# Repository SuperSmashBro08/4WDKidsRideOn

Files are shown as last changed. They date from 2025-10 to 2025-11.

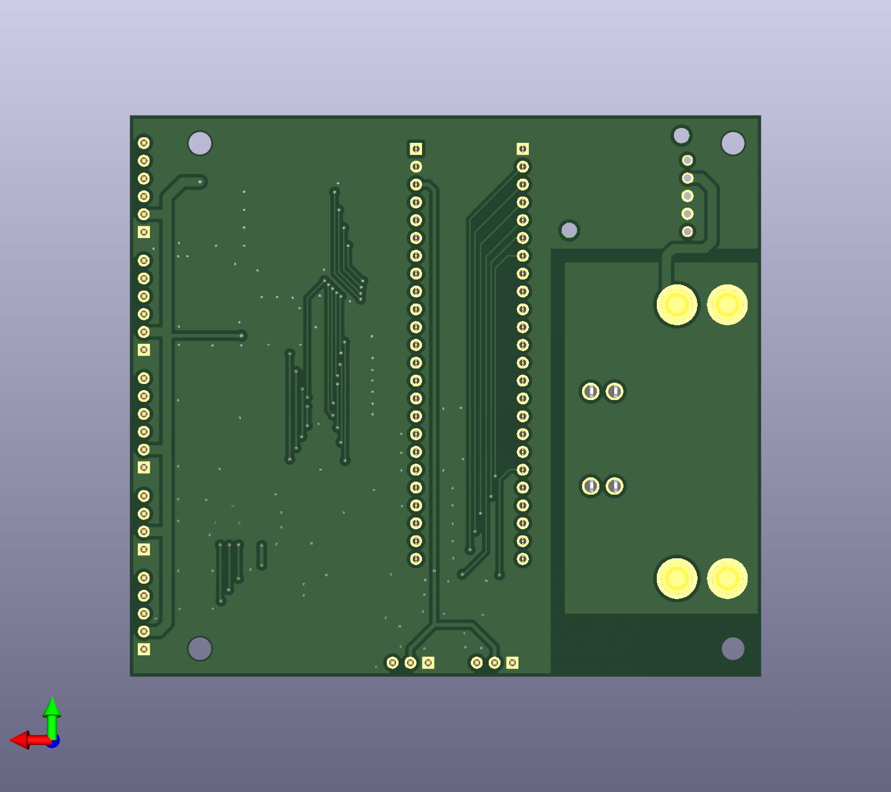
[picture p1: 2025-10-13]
hardware/PCB/Kids Ride On V3/Kids Ride On V3/Pdfs and images/bottom.jpg

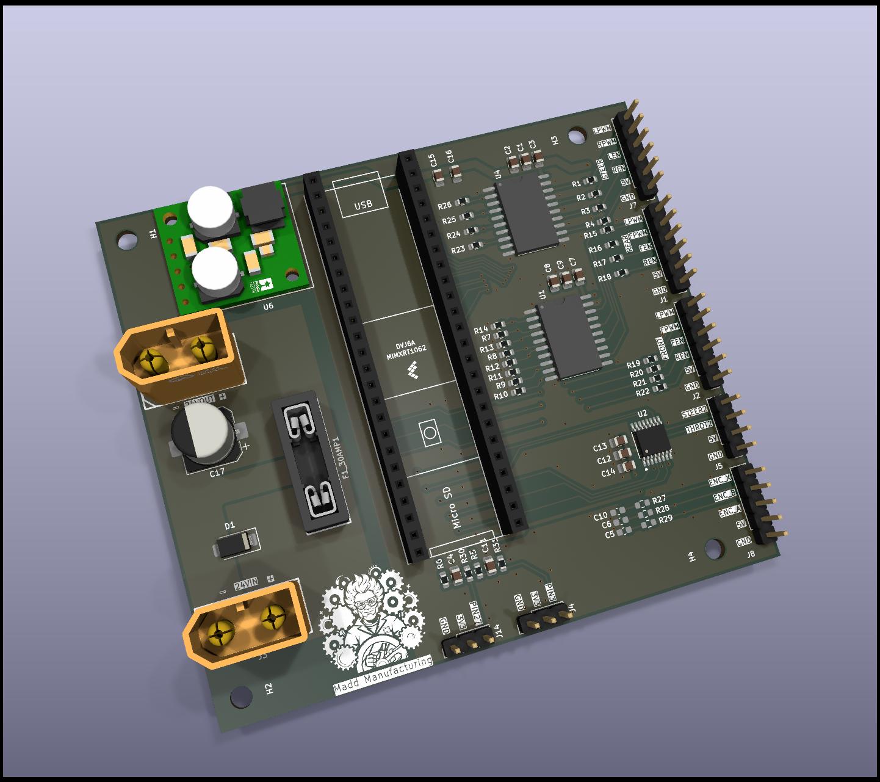
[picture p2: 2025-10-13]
hardware/PCB/Kids Ride On V3/Kids Ride On V3/Pdfs and images/3d.jpg

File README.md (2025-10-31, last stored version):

# ESP32 ↔ Teensy 4.1 OTA Workflow

This repository contains two coordinated sketches that allow an ESP32-S3 to deliver over-the-air
(OTA) firmware updates to a Teensy 4.1-based TNC. The ESP32 hosts a small web page where you upload
the Intel HEX file exported by the Arduino IDE. The Teensy runs a purpose-built stub that
handshakes with the ESP32, receives the HEX records, writes them directly into its internal QSPI
flash, and automatically reboots into the freshly programmed image.

The sections below walk through every step from wiring to flashing.

## Hardware overview

* **Teensy 4.1** running the OTA stub sketch found under `firmware/Teensy41_Target/teensystub`.
* **ESP32-S3** running the uploader sketch in `firmware/ESP32_Uploader/esp32_uploader`.
* **Serial link** – connect ESP32 GPIO43 → Teensy RX2 (pin 7) and ESP32 GPIO44 ← Teensy TX2 (pin 8).
  Share ground between the boards. Keep the wiring short (<15 cm) for clean 115200 baud links.
* **Optional debug USB** – connect the Teensy micro‑USB to a computer to monitor verbose logs while
  testing. The ESP32 USB serial console is also helpful for Wi‑Fi and OTA diagnostics.

## Preparing the firmware

1. Open the Teensy project you want to deploy in the Arduino IDE and select **Teensy 4.1** as the
   target board.
2. Use **Sketch → Export compiled Binary**. This generates a `.hex` file in the sketch folder.
3. (Optional) Rename the HEX file with the build date or version so you can identify it easily on
the ESP32 upload page.

## Building and loading the OTA stub

1. In the Arduino IDE open `firmware/Teensy41_Target/teensystub/teensystub.ino`.
2. Verify that the `OTA_TOKEN` matches the value in `firmware/ESP32_Uploader/esp32_uploader/secrets.h`.
   Changing the token requires reflashing **both** boards.
3. Click **Upload** to flash the stub onto the Teensy 4.1. The stub prints its firmware version and
   provides a small serial console (commands: `help`, `status`, `version`, `reboot`).
4. Leave the stub in place. Every subsequent OTA update will completely replace it with your real
   TNC firmware, so be sure to keep a copy handy if you ever need to revert.

## Flashing workflow (ESP32 as the OTA server)

1. Flash the ESP32 with `firmware/ESP32_Uploader/esp32_uploader.ino`, update Wi‑Fi credentials in
   `secrets.h`, and allow it to join your network. The serial console prints the IP address and the
   optional mDNS hostname (`esp32-teensy.local`).
2. Visit `http://<esp32-ip>/` in a browser. The page exposes a single file upload form.
3. Click **Choose File**, select the Teensy `.hex` binary, and press **Upload & Flash**.
4. The ESP32 performs the following automatically:
   * Opens the serial link to the Teensy and sends `HELLO <token>`.
   * Streams each Intel HEX record line-by-line (`BEGIN HEX`, `L …`, `END`).
   * Displays a live log containing acknowledgements for every line.
5. The Teensy stub validates every record, accumulates data into 4 KB sectors, erases/programs its
   internal flash, and acknowledges each line with `OK <n>`. When the last record arrives it sends a
   summary (`HEX OK …`) followed by `APPLIED`, waits one second, and triggers a software reset to
   boot into the newly flashed firmware.
6. The ESP32 page updates with a success message showing transfer statistics. If anything fails you
   will see the Teensy-provided error reason (checksum mismatch, unsupported record type, flash
   write failure, missing EOF, etc.).

## Recovery and troubleshooting

* If the Teensy reports `HEX FAIL` immediately after `BEGIN HEX`, ensure the `OTA_TOKEN` matches and
  that both boards are wired correctly. Any lingering serial data from previous runs should be
  cleared by resetting the Teensy.
* When a transfer aborts mid-stream, the Teensy keeps the original firmware. The stub only commits
  data after successfully writing each 4 KB sector and it does not reset until the entire image
  passes validation.
* To recover the stub after flashing a faulty firmware, press and hold the Teensy **Program** button
  and upload the stub again from the Arduino IDE via USB. Once the stub is running you can retry the
  OTA process.
* Use the Teensy USB console command `status` to inspect how many lines, bytes, sectors, and pages
  were processed in the most recent session. This mirrors the data returned to the ESP32 uploader.

## Safety notes

* The stub only accepts data inside the Teensy 4.1 flash address window (`0x6000_0000 – 0x6020_0000`).
  Any record outside that range is rejected before any sector is erased.
* Flash programming runs with interrupts temporarily disabled while a page is written. The LED on
  pin 13 continues to heartbeat so you can see the board is alive during a long update.
* After a successful OTA the stub reboots automatically. No additional hardware toggling of the
  Program pin is required.

With the steps above the entire flow—uploading the HEX file, streaming it to the Teensy, flashing,
and rebooting—happens end-to-end without manual intervention.

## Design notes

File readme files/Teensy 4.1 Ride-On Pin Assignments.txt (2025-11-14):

Teensy 4.1 Ride-On Pin Assignments
Steering (J7)
Teensy Pin	Label / Function	Board Header	Motor Controller Label
Pin 15	Steer LPWM	J7-6	Steer L_PWM
Pin 16	Steer RPWM	J7-5	Steer R_PWM
Pin 17	Steer L_EN	J7-4	Steer L_EN
Pin 18	Steer R_EN	J7-3	Steer R_EN

Front Motors (J2)
Teensy Pin	Label / Function	Board Header	Motor Controller Label
Pin 19	Front R_EN	J2-3	Front R_EN
Pin 20	Front L_EN	J2-4	Front L_EN
Pin 21	Front L_PWM	J2-5	Front L_PWM
Pin 22	Front R_PWM	J2-6	Front R_PWM

Rear Motors (J1)
Teensy Pin	Label / Function	Board Header	Motor Controller Label
Pin 23	Rear R_EN	J1-3	Rear R_EN
Pin 24	Rear L_EN	J1-4	Rear L_EN
Pin 25	Rear L_PWM	J1-5	Rear L_PWM
Pin 26	Rear R_PWM	J1-6	Rear R_PWM

Direction Switch (Shift Lever)
Teensy Pin	Label / Function	Board Header	Motor Controller 
Pin 10	Forward		
Pin 11	Reverse		

ESP32 Link (UART for OTA/Telnet)
Teensy Pin	Label / Function	Board Header	Motor Controller
Pin 7	RX2 (to ESP32 TX)		
Pin 8	TX2 (to ESP32 RX)		

Pots (Child Controls)
Teensy Pin	Label / Function	Board Header	Motor Controller
Pin 27	Foot Pedal (Throttle1)		
Pin 3	Steering Wheel (Steering1)		

Remote Override (RC Receiver)
Teensy Pin	Label / Function	Board Header	Motor Controller
Pin 5	Steering2		
Pin 4	Throttle2		

Gearbox Encoder (AMT-102V)
Teensy Pin	Label / Function	Board Header	Motor Controller
Pin 2	Encoder X		
Pin 1	Encoder B		
Pin 0	Encoder A

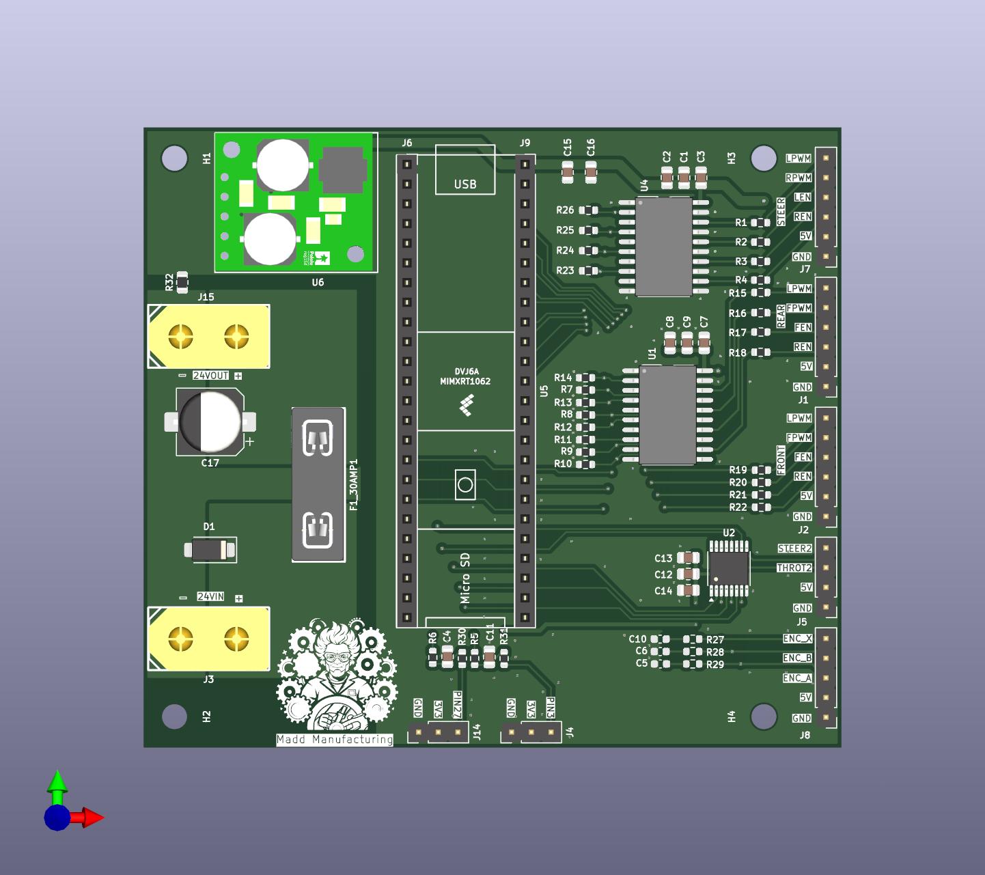
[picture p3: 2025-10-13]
hardware/PCB/Kids Ride On V3/Kids Ride On V3/Pdfs and images/TOP.jpg

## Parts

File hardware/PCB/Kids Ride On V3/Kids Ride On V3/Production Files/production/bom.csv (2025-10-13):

Designator | Footprint | Quantity | Value | LCSC Part #
C1, C11, C12, C15, C4, C7 | 0805 | 6 | 100nF | C49678
C10, C5, C6 | 0603 | 3 | 100pF | C14858
C13, C2, C8 | 0805 | 3 | 1uF | C28323
C14, C3, C9 | 0805 | 3 | 10uF | C15850
C16 | 0805 | 1 | 4.7uF | C98192
C17 | CP_Elec_8x10.5 | 1 | 220uF/35V | C5246556
D1 | D_SMA | 1 | SMAJ33A | C353454
F1_30AMP1 | FUSE-TH_4P-L19.8-W6.7_3557-2 | 1 | Fuse | C352820
J1, J2, J7 | PinHeader_1x06_P2.54mm_Vertical | 3 | Conn_01x06 | C492405
J14, J4 | PinHeader_1x03_P2.54mm_Vertical | 2 | Conn_01x03 | C2937625
J15, J3 | CONN-TH_XT60 | 2 | XT60-M. | C98733
J5 | PinHeader_1x04_P2.54mm_Vertical | 1 | Conn_01x04 | C2691448
J6, J9 | PinSocket_1x24_P2.54mm_Vertical | 2 | Conn_01x24 | C2883741
J8 | PinHeader_1x05_P2.54mm_Vertical | 1 | Conn_01x05 | C492404
R1, R15, R16, R17, R18, R19, R2, R20, R21, R22, R3, R4, R5, R6 | 0603 | 14 | 33R | C108661
R10, R11, R12, R13, R14, R23, R24, R25, R26, R7, R8, R9 | 0603 | 12 | 10k | C98220
R27, R28, R29, R30, R31 | 0603 | 5 | 100R | C105588
R32 | 0805 | 1 | 0R | C100045
U1, U4 | SOIC-20_L12.8-W7.5-P1.27-LS10.3-BL | 2 | SN74AHCT244 | C2675568
U2 | TSSOP-16_4.4x5mm_P0.65mm | 1 | CD74HC4050 | C352825
U6 | D24V50F5 | 1 | D24V50F5 | DNP

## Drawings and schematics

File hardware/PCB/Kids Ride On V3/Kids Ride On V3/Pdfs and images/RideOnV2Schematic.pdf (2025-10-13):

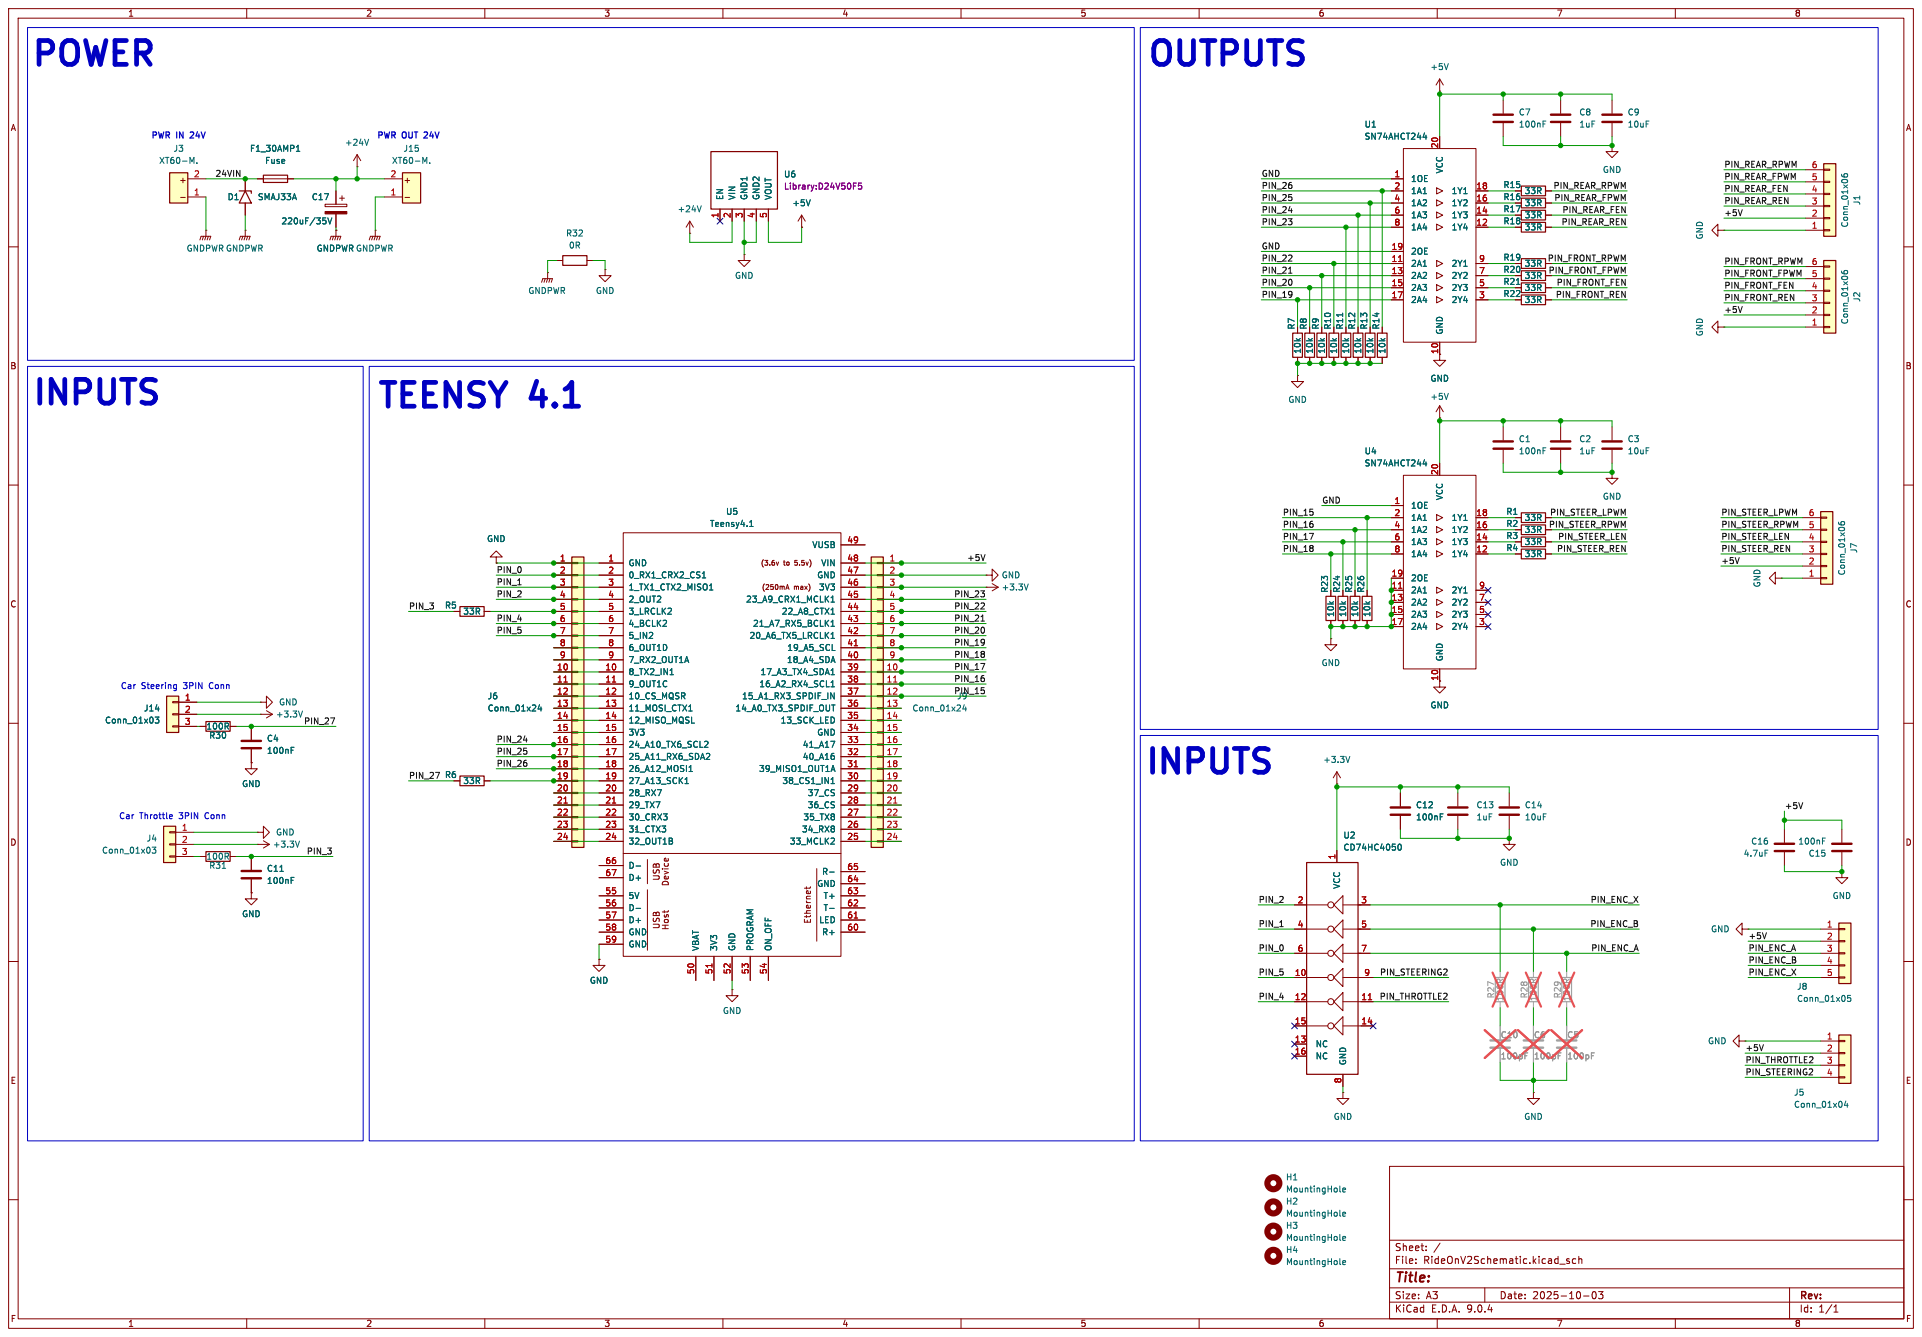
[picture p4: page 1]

Car Throttle 3PIN Conn Car Steering 3PIN Conn INPUTS

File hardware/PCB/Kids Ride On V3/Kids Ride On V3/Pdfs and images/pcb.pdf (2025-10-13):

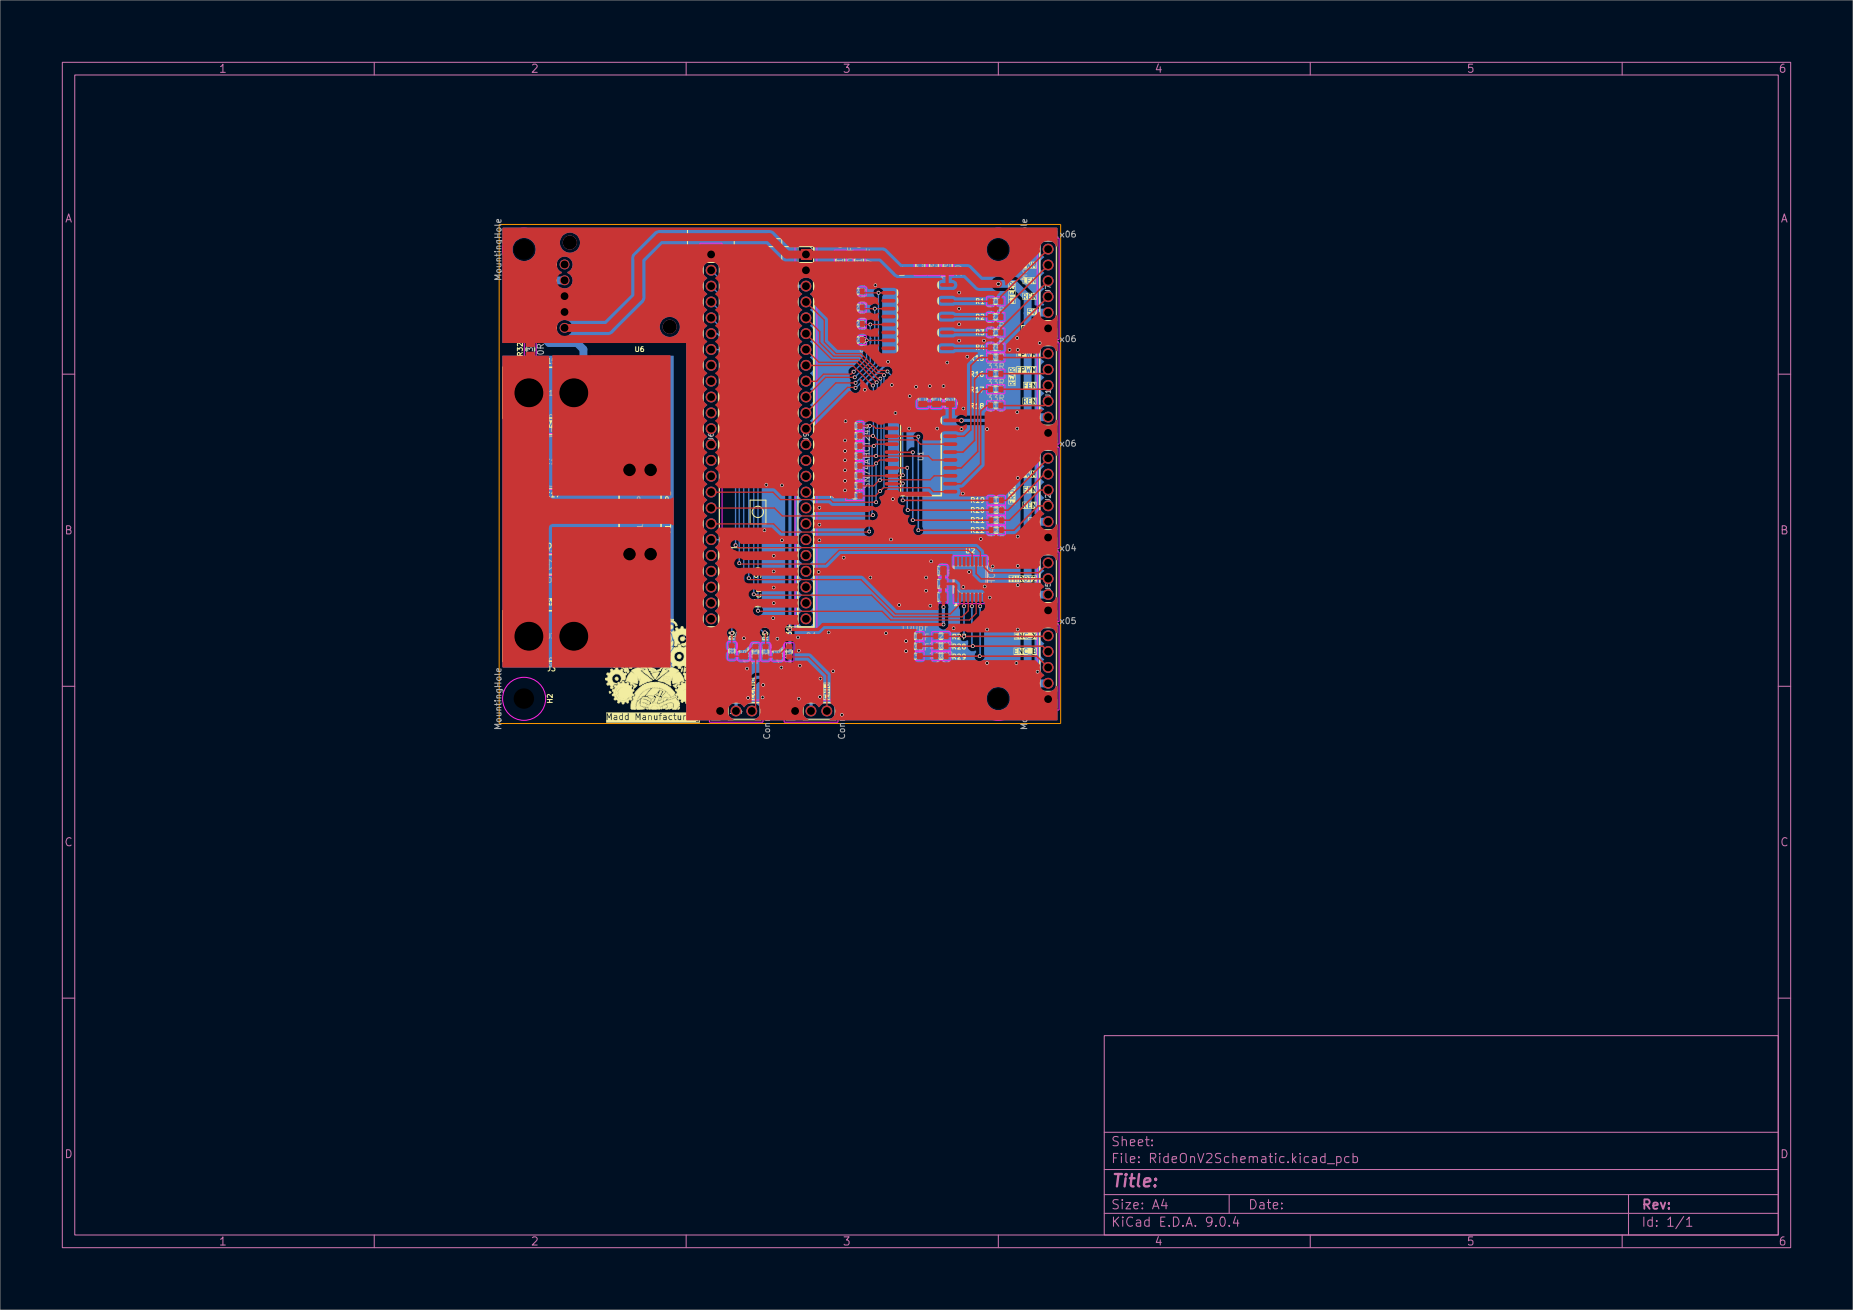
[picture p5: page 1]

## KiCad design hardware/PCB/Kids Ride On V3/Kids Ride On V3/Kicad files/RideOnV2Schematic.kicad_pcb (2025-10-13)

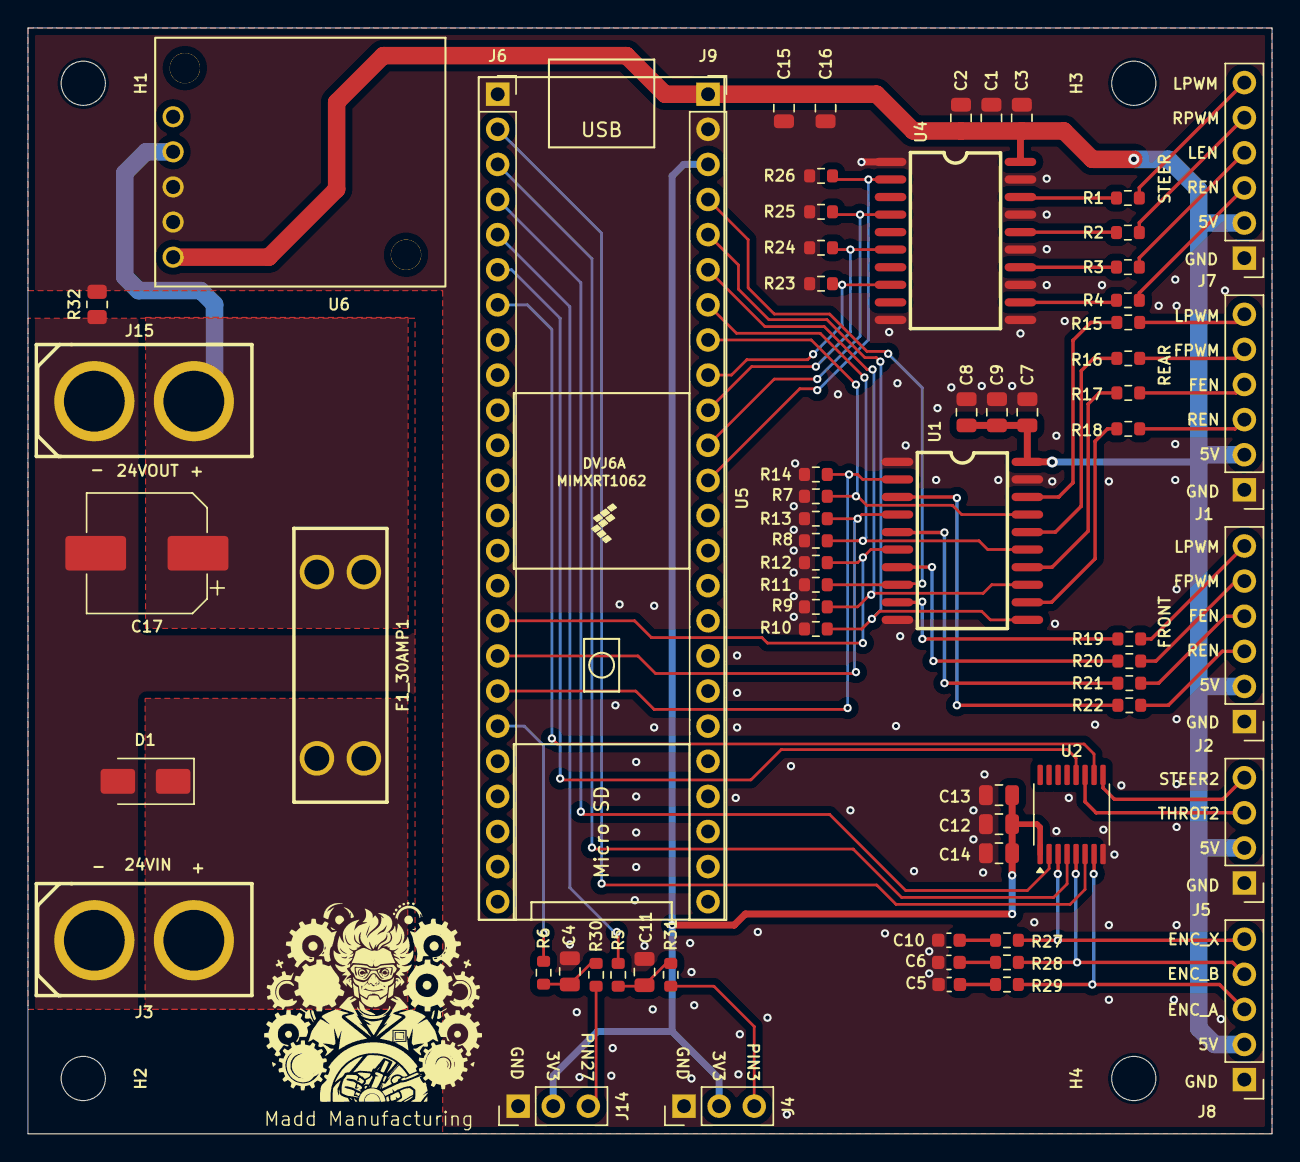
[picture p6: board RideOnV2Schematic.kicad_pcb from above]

Board: 2 copper layers, 90.0 x 80.0 mm, 71 parts (0 on the bottom side), 61 nets.

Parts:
C1, C4, C7, C11, C12, C15: 100nF; C_0805_2012Metric
C2, C8, C13: 1uF; C_0805_2012Metric
C3, C9, C14: 10uF; C_0805_2012Metric
C5, C6, C10: 100pF; C_0603_1608Metric
C16: 4.7uF; C_0805_2012Metric
C17: 220uF/35V; CP_Elec_8x10.5
D1: SMAJ33A; D_SMA
F1_30AMP1: Fuse; FUSE-TH_4P-L19.8-W6.7_3557-2
H1, H2, H3, H4: MountingHole; MountingHole_3.2mm_M3
J1, J2, J7: Conn_01x06; PinHeader_1x06_P2.54mm_Vertical
J3, J15: XT60-M.; CONN-TH_XT60
J4, J14: Conn_01x03; PinHeader_1x03_P2.54mm_Vertical
J5: Conn_01x04; PinHeader_1x04_P2.54mm_Vertical
J6, J9: Conn_01x24; PinSocket_1x24_P2.54mm_Vertical
J8: Conn_01x05; PinHeader_1x05_P2.54mm_Vertical
R1, R2, R3, R4, R5, R6, R15, R16, R17, R18, R19, R20, R21, R22: 33R; R_0603_1608Metric
R7, R8, R9, R10, R11, R12, R13, R14, R23, R24, R25, R26: 10k; R_0603_1608Metric
R27, R28, R29, R30, R31: 100R; R_0603_1608Metric
R32: 0R; R_0805_2012Metric
U1, U4: SN74AHCT244; SOIC-20_L12.8-W7.5-P1.27-LS10.3-BL
U2: CD74HC4050; TSSOP-16_4.4x5mm_P0.65mm
U5: Teensy4.1; Teensy41
U6: D24V50F5

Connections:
+3.3V: C12.1, C13.1, C14.1, J4.2, J9.3, J14.2, U2.1 (VCC)
+5V: C1.1, C2.1, C3.1, C7.1, C8.1, C9.1, C15.2, C16.2, J1.2, J2.2, J5.2, J7.2, J8.2, J9.1, U1.20 (VCC), U4.20 (VCC), U6.5 (VOUT)
+24V: C17.1, F1_30AMP1.1, J15.2, U6.2 (VIN)
/24VIN: D1.1 (A1), F1_30AMP1.2, J3.2
/PIN_0: J6.2, U2.6
/PIN_1: J6.3, U2.4
/PIN_2: J6.4, U2.2
/PIN_3: C11.1, R5.1, R31.1
/PIN_4: J6.6, U2.12
/PIN_5: J6.7, U2.10
/PIN_15: J9.12, R26.1, U4.2 (1A1)
/PIN_16: J9.11, R25.1, U4.4 (1A2)
/PIN_17: J9.10, R24.1, U4.6 (1A3)
/PIN_18: J9.9, R23.1, U4.8 (1A4)
/PIN_19: J9.8, R7.1, U1.17 (2A4)
/PIN_20: J9.7, R8.1, U1.15 (2A3)
/PIN_21: J9.6, R9.1, U1.13 (2A2)
/PIN_22: J9.5, R10.1, U1.11 (2A1)
/PIN_23: J9.4, R11.1, U1.8 (1A4)
/PIN_24: J6.16, R12.1, U1.6 (1A3)
/PIN_25: J6.17, R13.1, U1.4 (1A2)
/PIN_26: J6.18, R14.1, U1.2 (1A1)
/PIN_27: C4.1, R6.1, R30.1
/PIN_ENC_A: J8.3, R29.2, U2.7
/PIN_ENC_B: J8.4, R28.2, U2.5
/PIN_ENC_X: J8.5, R27.2, U2.3
/PIN_FRONT_FEN: J2.4, R21.2
/PIN_FRONT_FPWM: J2.5, R20.2
/PIN_FRONT_REN: J2.3, R22.2
/PIN_FRONT_RPWM: J2.6, R19.2
/PIN_REAR_FEN: J1.4, R17.2
/PIN_REAR_FPWM: J1.5, R16.2
/PIN_REAR_REN: J1.3, R18.2
/PIN_REAR_RPWM: J1.6, R15.2
/PIN_STEERING2: J5.4, U2.9
/PIN_STEER_LEN: J7.4, R3.2
/PIN_STEER_LPWM: J7.6, R1.2
/PIN_STEER_REN: J7.3, R4.2
/PIN_STEER_RPWM: J7.5, R2.2
/PIN_THROTTLE2: J5.3, U2.11
GND: C1.2, C2.2, C3.2, C4.2, C5.2, C6.2, C7.2, C8.2, C9.2, C10.2, C11.2, C12.2, C13.2, C14.2, C15.1, C16.1, J1.1, J2.1, J4.1, J5.1, J6.1, J7.1, J8.1, J9.2, J14.1, R7.2, R8.2, R9.2, R10.2, R11.2, R12.2, R13.2, R14.2, R23.2, R24.2, R25.2, R26.2, R32.2, U1.1 (1OE), U1.10 (GND), U1.19 (2OE), U2.8 (GND), U4.1 (1OE), U4.10 (GND), U4.11 (2A1), U4.13 (2A2), U4.15 (2A3), U4.17 (2A4), U4.19 (2OE), U6.3 (GND1), U6.4 (GND2)
GNDPWR: C17.2, D1.2 (A2), J3.1, J15.1, R32.1
unnamed: C5.1, R29.1
unnamed: C6.1, R28.1
unnamed: C10.1, R27.1
unnamed: J4.3, R31.2
unnamed: J6.5, R5.2
unnamed: J6.19, R6.2
unnamed: J14.3, R30.2
unnamed: R15.1, U1.18 (1Y1)
unnamed: R16.1, U1.16 (1Y2)
unnamed: R17.1, U1.14 (1Y3)
unnamed: R18.1, U1.12 (1Y4)
unnamed: R19.1, U1.9 (2Y1)
unnamed: R20.1, U1.7 (2Y2)
unnamed: R21.1, U1.5 (2Y3)
unnamed: R22.1, U1.3 (2Y4)
unnamed: R1.1, U4.18 (1Y1)
unnamed: R2.1, U4.16 (1Y2)
unnamed: R3.1, U4.14 (1Y3)
unnamed: R4.1, U4.12 (1Y4)

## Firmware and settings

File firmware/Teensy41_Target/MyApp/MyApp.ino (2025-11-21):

// ============ MyApp.ino  ============
//
// Features:
// - RAW snapshot line every ~30 ms: S1/T1/S2/T2/FNR/AS + throttle levels (both sources, raw view)
// - STEER line: steering target (L/C/R), current angle, steer source, throttle source, drive ON/OFF
// - THR line: effective throttle source (T1/T2) and speed level OFF/LOW/MED/HIGH
// - DRIVE logic:
//      • FNR = neutral → drive OFF
//      • FNR = forward → M1/M2 drive forward at OFF/LOW/MED/HIGH
//      • FNR = reverse → M1/M2 drive reverse at OFF/LOW/MED/HIGH
//      • Only the active throttle source (ThrSrc) affects drive speed
// - ESP32 angle stream over Serial2 via OtaUpdater hook
//   expected line from ESP32: "AS,<raw>,<deg>"
// - Steering motor driver: BTS7960 on pins 15..18 (LPWM/RPWM/L_EN/R_EN)
// - Front (M1) and Rear (M2) drive BTS7960 on pins 19..26
// - Steering selection by thirds (S1 or S2):
//      S1: 420..2870 (left/center/right thirds)
//      S2: 1000..2000 µs (left/center/right thirds)
// - Throttle shaping:
//      • T1 pedal raw window: 1108 = Off, 3140 = Full
//        - mapped 0..1000 only across [1108..3140]
//        - <=30 in that normalized space = Off (Lv0), rest → Lv1/Lv2/Lv3
//      • T2 RC: signed around 1500 µs, magnitude → Lv1/Lv2/Lv3
// - Control source switching:
//      • Default source: S1/T1
//      • Hold T2 reverse (≤1200 µs) for 3 s → switch to S2/T2
//      • After handover, T2 must pass through neutral to arm
//      • When S2 and T2 both sit near neutral (~1500 ± 40 µs) for 10 s
//        → auto-return to S1/T1, regardless of S1/T1 state
// - Steering motor drive is disabled by default (STEER_DRIVE_ENABLE=0)
//
// =============================================

#ifndef ENABLE_TEENSY_BINARY_TELEM
#define ENABLE_TEENSY_BINARY_TELEM 0
#endif

#include <Arduino.h>
#include <stdarg.h>
#include <string.h>
#include <math.h>
#include <limits.h>
#include "OtaUpdater.h"
#include "OtaConsole.h"

#ifndef IRAM_ATTR
#define IRAM_ATTR
#endif
#ifndef digitalReadFast
#define digitalReadFast digitalRead
#endif

// ---------- App identity ----------
#define APP_FW_VERSION   "V 3.6.1"

// ---------- Blink ----------
#define LED_PIN          13
#define BLINK_MS         500

// ---------- Raw-mirror mode switch ----------
#define RAW_MIRROR_MODE  1   // keep raw stream on

// ---------- IO pins ----------
// Gear F/N/R switch inputs (active LOW with pullups)
static constexpr uint8_t PIN_FWD    = 10;
static constexpr uint8_t PIN_REV    = 11;

// Steering 1 and Throttle 1 (analog)
static constexpr uint8_t PIN_POT_S1 = 14;  // steering analog (wheel/pot)
static constexpr uint8_t PIN_POT_T1 = 27;  // throttle analog (foot pedal)

// RC steering/throttle (S2/T2) PWM inputs
static constexpr uint8_t PIN_RC_S   = 4;   // RC steer PWM in (S2)
static constexpr uint8_t PIN_RC_T   = 5;   // RC throttle PWM in (T2)

// Steering BTS7960 (steer motor)
static constexpr uint8_t PIN_STEER_LPWM = 15;  // J7-6
static constexpr uint8_t PIN_STEER_RPWM = 16;  // J7-5
static constexpr uint8_t PIN_STEER_LEN  = 17;  // J7-4
static constexpr uint8_t PIN_STEER_REN  = 18;  // J7-3

// Drive motor outputs (M1 Front, M2 Rear)
// Front Motors (M1)
static constexpr uint8_t PIN_M1_R_EN  = 19;  // J2-3  Front R_EN
static constexpr uint8_t PIN_M1_L_EN  = 20;  // J2-4  Front L_EN
static constexpr uint8_t PIN_M1_L_PWM = 21;  // J2-5  Front L_PWM
static constexpr uint8_t PIN_M1_R_PWM = 22;  // J2-6  Front R_PWM

// Rear Motors (M2)
static constexpr uint8_t PIN_M2_R_EN  = 23;  // J1-3  Rear R_EN
static constexpr uint8_t PIN_M2_L_EN  = 24;  // J1-4  Rear L_EN
static constexpr uint8_t PIN_M2_L_PWM = 25;  // J1-5  Rear L_PWM
static constexpr uint8_t PIN_M2_R_PWM = 26;  // J1-6  Rear R_PWM

// ---------- ADC helpers ----------
static constexpr float    ADC_VREF    = 3.3f;
static constexpr int      ADC_MAX     = 4095;

// ---------- Logging sink control ----------
enum class LogSink : uint8_t { OTA, USB, BOTH };
static LogSink g_logSink = LogSink::OTA;   // OTA-only by default

// Force every line sent to ESP32 console to start with "S "
static void LOG_raw(const char* s){
  const bool alreadyS = (s && s[0]=='S' && s[1]==' ');
  if (g_logSink==LogSink::OTA || g_logSink==LogSink::BOTH){
    if (alreadyS) OtaConsole::printf("%s", s);
    else          OtaConsole::printf("S %s", s);
  }
  if (g_logSink==LogSink::USB || g_logSink==LogSink::BOTH) Serial.print(s);
}
static void SLOGF(const char* fmt, ...){
  char buf[256];
  va_list ap; va_start(ap, fmt); vsnprintf(buf, sizeof(buf), fmt, ap); va_end(ap);
  LOG_raw(buf);
}

// ================= NAMESPACE MM =================
namespace MM {

// ===== Gear / FNR =====
enum FnrState : uint8_t { FNR_NEU=0, FNR_FWD=1, FNR_REV=2, FNR_FAULT=3 };
static FnrState g_fnr = FNR_NEU;
static inline const char* fnrWord(FnrState s){
  switch(s){ case FNR_FWD: return "forward"; case FNR_REV: return "reverse";
             case FNR_NEU: return "neutral"; default: return "fault"; }
}

// ===== Live values =====
static uint16_t g_s1=0, g_t1=0;                  // raw analog (S1 wheel, T1 pedal)
static volatile uint32_t rcS_rise_us=0, rcS_last_update_us=0;
static volatile uint16_t rcS_width_us=1500;      // S2 µs
static volatile uint32_t rcT_rise_us=0, rcT_last_update_us=0;
static volatile uint16_t rcT_width_us=1500;      // T2 µs
static int16_t  g_s2_us=1500, g_t2_us=1500;      // copies each tick

// ===== RC PWM capture (interrupt) =====
static constexpr uint16_t RC_MIN_US=1000, RC_MID_US=1500, RC_MAX_US=2000, RC_DB_US=20;

static void IRAM_ATTR isrRcSteer(){
  uint32_t now=micros();
  if(digitalReadFast(PIN_RC_S)) rcS_rise_us=now;
  else {
    uint32_t w=now-rcS_rise_us;
    if(w<=3000){
      rcS_width_us=(uint16_t)w;
      rcS_last_update_us=now;
    }
  }
}
static void IRAM_ATTR isrRcThrottle(){
  uint32_t now=micros();
  if(digitalReadFast(PIN_RC_T)) rcT_rise_us=now;
  else {
    uint32_t w=now-rcT_rise_us;
    if(w<=3000){
      rcT_width_us=(uint16_t)w;
      rcT_last_update_us=now;
    }
  }
}

// ===== Convenience maps =====
static inline int16_t clamp_i16(int32_t v, int16_t lo, int16_t hi){
  if(v<lo) return lo;
  if(v>hi) return hi;
  return (int16_t)v;
}

static inline int16_t mapRcSteer_us_to_1000(int16_t us){
  if(us<RC_MIN_US) us=RC_MIN_US;
  if(us>RC_MAX_US) us=RC_MAX_US;
  int32_t x=(int32_t)us-RC_MID_US;
  if (abs(x)<=RC_DB_US) return 0;
  return clamp_i16((x*1000)/(RC_MAX_US-RC_MID_US), -1000, 1000);
}

// Throttle-2: raw-to-0..1000 (forward magnitude helper)
static inline int16_t mapRcThr_us_to_1000(int16_t us){
  if(us<RC_MIN_US) us=RC_MIN_US;
  if(us>RC_MAX_US) us=RC_MAX_US;
  int32_t out=((int32_t)us-RC_MIN_US)*1000/(RC_MAX_US-RC_MIN_US);
  if(out<0)out=0;
  if(out>1000)out=1000;
  return (int16_t)out;
}

// Throttle-2: signed around 1500 µs: -1000 .. 0 .. +1000
static inline int16_t mapRcThrSigned_us_to_1000(int16_t us){
  if(us<RC_MIN_US) us=RC_MIN_US;
  if(us>RC_MAX_US) us=RC_MAX_US;
  int32_t x = (int32_t)us - RC_MID_US;
  if (abs(x) <= RC_DB_US) return 0;
  int32_t span = (RC_MAX_US - RC_MID_US);
  int32_t v = (x * 1000) / span;
  return clamp_i16(v, -1000, 1000);
}

// T1 raw window: 1108 (off) to 3140 (full)
static constexpr uint16_t T1_MIN_RAW = 1108;
static constexpr uint16_t T1_MAX_RAW = 3140;

// T1 mapped to 0..1000 but only across [T1_MIN_RAW..T1_MAX_RAW]
static inline int16_t mapT1_to_1000(uint16_t t1raw){
  if (t1raw <= T1_MIN_RAW) return 0;
  if (t1raw >= T1_MAX_RAW) return 1000;
  uint32_t num = (uint32_t)(t1raw - T1_MIN_RAW) * 1000u;
  uint32_t den = (uint32_t)(T1_MAX_RAW - T1_MIN_RAW);
  return (int16_t)(num / den);
}

// ===== Samples =====
static void sampleAnalog(){
  g_s1=analogRead(PIN_POT_S1);
  g_t1=analogRead(PIN_POT_T1);
}
static void sampleFnr(){
  const bool fwd_low=(digitalRead(PIN_FWD)==LOW), rev_low=(digitalRead(PIN_REV)==LOW);
  if( fwd_low &&  rev_low) g_fnr=FNR_FAULT;
  else if( fwd_low && !rev_low) g_fnr=FNR_FWD;
  else if(!fwd_low &&  rev_low) g_fnr=FNR_REV;
  else g_fnr=FNR_NEU;
}

} // namespace MM

// ======= Angle stream (from ESP32) + helpers ==================================
static volatile uint16_t g_as_raw = 0;
static volatile float    g_as_deg = NAN;
static volatile uint32_t g_as_ms  = 0;

static inline bool angleFresh(uint32_t maxAgeMs);
static bool angleSnapshot(uint16_t& rawOut, float& degOut);

extern "C" bool OtaUserHandleLine(const char* line) {
  if (!line || !*line) return false;
  if (strcmp(line, "PING") == 0) {
    Serial2.println("PONG");
    return true;
  }
  if (strcmp(line, "VERSION") == 0) {
    Serial2.print("FW "); Serial2.println(APP_FW_VERSION);
    Serial2.println("FLASHERX READY");
    return true;
  }

  // Angle packets from ESP32: AS,<raw>,<deg>
  if (line[0]=='A' && line[1]=='S' && line[2]==',') {
    const char* p = line + 3;
    const char* comma = strchr(p, ',');
    if (!comma) return false;
    uint16_t raw = (uint16_t)strtoul(p, nullptr, 10);
    float    deg = atof(comma + 1);
    noInterrupts();
    g_as_raw=raw;
    g_as_deg=deg;
    g_as_ms=millis();
    interrupts();
    return true;
  }
  return false;
}

static inline bool angleFresh(uint32_t maxAgeMs) {
  uint32_t age = millis() - g_as_ms;
  return (g_as_ms != 0) && (age <= maxAgeMs) && !isnan(g_as_deg);
}
static bool angleSnapshot(uint16_t& rawOut, float& degOut) {
  uint16_t raw; float deg; uint32_t stamp;
  noInterrupts();
  raw=g_as_raw; deg=g_as_deg; stamp=g_as_ms;
  interrupts();
  if (stamp == 0 || isnan(deg)) return false;
  if ((millis() - stamp) > 200)  return false;
  rawOut = raw;
  degOut = deg;
  return true;
}

// ======= Telemetry (optional binary to ESP32) ==================================
static inline int16_t toCenti(float v){
  float scaled = v * 100.0f;
  scaled += (scaled >= 0.0f) ? 0.5f : -0.5f;
  long val = (long)scaled;
  if (val > INT16_MAX) val = INT16_MAX;
  if (val < INT16_MIN) val = INT16_MIN;
  return (int16_t)val;
}

#if ENABLE_TEENSY_BINARY_TELEM
// (binary telemetry omitted)
#endif

// ====================== LIMITS / THIRDS ======================
#define AS_LIMITS_SOURCE   1   // 0 = RAW ticks, 1 = degrees
#define AS_LEFT_RAW_PHOTO   1465
#define AS_RIGHT_RAW_PHOTO  2300
#define AS_CENTER_RAW_PHOTO ((AS_LEFT_RAW_PHOTO+AS_RIGHT_RAW_PHOTO)/2)
#define AS_LEFT_DEG_PHOTO    129.00f
#define AS_RIGHT_DEG_PHOTO   202.00f
#define AS_CENTER_DEG_PHOTO  ((AS_LEFT_DEG_PHOTO+AS_RIGHT_DEG_PHOTO)*0.5f)

static const float LIMIT_SOFT_CUSHION_DEG = 2.5f;
static const float LIMIT_HARD_CUSHION_DEG = 0.8f;

static inline float ticksToDeg_u12(uint16_t t12){
  return (360.0f * (float)t12) / 4096.0f;
}

// ====================== CONTROL SOURCE / THROTTLE LEVELS ======================
enum class SteerSrc : uint8_t { S1, S2 };
enum class ThrSrc   : uint8_t { T1, T2 };
static SteerSrc g_steerSrc = SteerSrc::S1;   // default
static ThrSrc   g_thrSrc   = ThrSrc::T1;     // default

// 4-level throttle classification (0=Off,1=Low,2=Med,3=High)
static int8_t g_t1Level = 0;   // always start OFF
static int8_t g_t2Level = 0;   // always start OFF

// Your S1 thirds: 420..2870
static constexpr uint16_t S1_MIN = 420;
static constexpr uint16_t S1_MAX = 2870;
// S2 thirds: 1000..2000 µs
static constexpr uint16_t S2_MIN = 1000;
static constexpr uint16_t S2_MAX = 2000;

// Cut points: [MIN .. LEFT_END) | [LEFT_END .. CENTER_END) | [CENTER_END .. MAX]
static inline void thirds_u16(uint16_t lo, uint16_t hi, uint16_t& L_end, uint16_t& C_end){
  uint32_t span = (uint32_t)hi - (uint32_t)lo;
  uint16_t third = (uint16_t)(span / 3u);
  L_end = (uint16_t)(lo + third);
  C_end = (uint16_t)(lo + 2u*third);
}
static uint16_t S1_LEFT_END=0, S1_CENTER_END=0;
static uint16_t S2_LEFT_END=0, S2_CENTER_END=0;

// Hand-over conditions
static constexpr uint16_t RC_REVERSE_THRESH_US = 1200;    // ≤ this is reverse
static constexpr uint32_t RC_REVERSE_HOLD_MS   = 3000;    // 3 s
static uint32_t g_rcReverseStartMs = 0;

// Neutral detection (deadbands)
static constexpr uint16_t T2_NEUTRAL_DB_US   = 40;        // ~±40 µs around 1500
static constexpr uint16_t T2_NEUTRAL_CTR_US  = 1500;

static constexpr uint16_t S2_NEUTRAL_DB_US   = 40;        // ~±40 µs around 1500 for steering
static constexpr uint16_t S2_NEUTRAL_CTR_US  = 1500;

// T1 "zero" deadband in T1 0..1000 space
static constexpr int16_t  T1_NEUTRAL_DB_MAP = 30;         // small off deadband

// Throttle level split points (magnitude in 0..1000)
static constexpr int16_t  THR_LVL1_MAX_01 = 333;          // Low
static constexpr int16_t  THR_LVL2_MAX_01 = 666;          // Med
static constexpr int16_t  THR_LVL3_MAX_01 = 1000;         // High

// Auto-return timer when S2 and T2 are neutral
static constexpr uint32_t AUTO_RETURN_MS     = 10000;     // 10 s
static uint32_t g_rcNeutralStartMs = 0;

// T2 throttle arming
static bool g_t2Armed = false;

// Disable steering motor drive until we’re ready
#define STEER_DRIVE_ENABLE 0

// Disable drive motors until we're ready
#define DRIVE_ENABLE       1

// ---- Neutral helpers ----
static inline bool isT2Neutral(uint16_t us){
  return (us >= (T2_NEUTRAL_CTR_US - T2_NEUTRAL_DB_US)) &&
         (us <= (T2_NEUTRAL_CTR_US + T2_NEUTRAL_DB_US));
}
static inline bool isS2Neutral(uint16_t us){
  return (us >= (S2_NEUTRAL_CTR_US - S2_NEUTRAL_DB_US)) &&
         (us <= (S2_NEUTRAL_CTR_US + S2_NEUTRAL_DB_US));
}

// ---- Throttle level classification ----
// Return 0..3 for Off/Low/Med/High
static inline int8_t classifyThrottle01(int16_t v01, int16_t deadband){
  if (v01 <= deadband)        return 0; // Off
  if (v01 <= THR_LVL1_MAX_01) return 1; // Low
  if (v01 <= THR_LVL2_MAX_01) return 2; // Med
  return 3;                               // High
}

static inline int8_t classifyThrottleSigned(int16_t vSigned, int16_t deadbandAbs){
  int16_t a = abs(vSigned);
  if (a <= deadbandAbs)        return 0; // Off
  if (a <= THR_LVL1_MAX_01)    return 1; // Low
  if (a <= THR_LVL2_MAX_01)    return 2; // Med
  return 3;                               // High
}

static inline const char* thrLevelWord(int8_t lvl){
  switch (lvl){
    case 0:  return "OFF";
    case 1:  return "LOW";
    case 2:  return "MED";
    case 3:  return "HIGH";
    default: return "?";
  }
}

// ======== Steering controller ==================================================
namespace Steer {
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
void loop(){
  using namespace MM;

  // OTA tick
  OtaUpdater::tick();

  // ~33 Hz sampling / logic + drive tick
  static uint32_t t_sample=0;
  const uint32_t nowUs = micros();
  if (nowUs - t_sample >= 30000){ // ~30ms
    t_sample = nowUs;

    uint32_t rcS_last_us, rcT_last_us;
    // Copy RC widths atomically
    noInterrupts();
    g_s2_us = rcS_width_us;
    g_t2_us = rcT_width_us;
    rcS_last_us = rcS_last_update_us;
    rcT_last_us = rcT_last_update_us;
    interrupts();

    // Sample raw and FNR
    sampleAnalog();
    sampleFnr();

    // ----- Throttle level classification -----
    // T1: mapped 0..1000 using raw window [1108..3140]
    const int16_t t1_map = mapT1_to_1000(g_t1);
    g_t1Level = classifyThrottle01(t1_map, T1_NEUTRAL_DB_MAP);

    // T2: signed around 1500 µs; direction via sign, level via |v|
    const int16_t t2_signed = mapRcThrSigned_us_to_1000(g_t2_us);
    g_t2Level = classifyThrottleSigned(t2_signed, THR_LVL1_MAX_01 / 10); // tiny DB, mostly from isT2Neutral

    // If T2 not armed yet and is the active throttle, treat as Off for drive
    if (g_thrSrc == ThrSrc::T2 && !g_t2Armed){
      // keep g_t2Level for RAW display, but effective level will be forced to 0 below
    }

    // ---- Control handover logic ----
    // 1) Default S1/T1. If T2 held reverse 3s → switch to S2/T2
    if (g_steerSrc == SteerSrc::S1 && g_thrSrc == ThrSrc::T1){
      if (g_t2_us <= RC_REVERSE_THRESH_US){
        if (g_rcReverseStartMs == 0) g_rcReverseStartMs = millis();
        else if ((millis() - g_rcReverseStartMs) >= RC_REVERSE_HOLD_MS){
          g_steerSrc = SteerSrc::S2;
          g_thrSrc   = ThrSrc::T2;
          g_t2Armed  = false; // must pass through neutral first
          SLOGF("S SRC -> steer=S2 throttle=T2 (T2 reverse hold)\r\n");
        }
      } else {
        g_rcReverseStartMs = 0; // broke the hold
      }
    }

    // 2) If on T2, require neutral pass to arm
    if (g_thrSrc == ThrSrc::T2 && !g_t2Armed){
      if (isT2Neutral(g_t2_us)){
        g_t2Armed = true;
        SLOGF("S T2 ARMED (neutral seen)\r\n");
      }
    }

    // 3) Auto-return to S1/T1 when S2 and T2 are neutral 10 s (ignore S1/T1)
    if (g_steerSrc == SteerSrc::S2 && g_thrSrc == ThrSrc::T2) {
      bool rcBothNeutral = isS2Neutral(g_s2_us) && isT2Neutral(g_t2_us);
      if (rcBothNeutral){
        if (g_rcNeutralStartMs == 0) g_rcNeutralStartMs = millis();
        else if ((millis() - g_rcNeutralStartMs) >= AUTO_RETURN_MS){
          if (g_steerSrc != SteerSrc::S1 || g_thrSrc != ThrSrc::T1){
            g_steerSrc = SteerSrc::S1;
            g_thrSrc   = ThrSrc::T1;
            g_rcReverseStartMs = 0;
            g_t2Armed = false;
            g_t2Level = 0;
            SLOGF("S SRC -> steer=S1 throttle=T1 (auto-return S2/T2 idle)\r\n");
          }
        }
      } else {
        g_rcNeutralStartMs = 0;
      }
    } else {
      g_rcNeutralStartMs = 0;
    }

    // Effective throttle (only selected source actually drives)
    int8_t effThrLevel = 0;
    const char* effSrcStr = (g_thrSrc==ThrSrc::T1) ? "T1" : "T2";

    if (g_thrSrc == ThrSrc::T1){
      effThrLevel = g_t1Level;
    } else {
      // T2: if not armed, force OFF for drive
      effThrLevel = g_t2Armed ? g_t2Level : 0;
    }

    // Maps for visualization
    const int16_t s2_map = mapRcSteer_us_to_1000(g_s2_us);
    const int16_t t2_map = mapRcThr_us_to_1000(g_t2_us);

    // Angle snapshot for RAW
    uint16_t as_raw = 0;
    float    as_deg = 0.0f;
    bool     haveAngle = angleSnapshot(as_raw, as_deg);

#if RAW_MIRROR_MODE
    if (haveAngle) {
      SLOGF(
        "S RAW S1=%u  T1=%u(%d,Lv%d)  S2_us=%d(%d)  T2_us=%d(%d,Lv%d)  "
        "AS=%u(%.2f)  FNR=%s\r\n",
        (unsigned)g_s1,
        (unsigned)g_t1, (int)t1_map, (int)g_t1Level,
        (int)g_s2_us, (int)s2_map,
        (int)g_t2_us, (int)t2_map, (int)g_t2Level,
        (unsigned)as_raw, (double)as_deg,
        fnrWord(g_fnr)
      );
    } else {
      SLOGF(
        "S RAW S1=%u  T1=%u(%d,Lv%d)  S2_us=%d(%d)  T2_us=%d(%d,Lv%d)  "
        "AS=---  FNR=%s\r\n",
        (unsigned)g_s1,
        (unsigned)g_t1, (int)t1_map, (int)g_t1Level,
        (int)g_s2_us, (int)s2_map,
        (int)g_t2_us, (int)t2_map, (int)g_t2Level,
        fnrWord(g_fnr)
      );
    }

    // Throttle summary (effective source + level)
    SLOGF("S THR src=%s lvl=%s t1Lv=%d t2Lv=%d t2Arm=%s\r\n",
          effSrcStr, thrLevelWord(effThrLevel),
          (int)g_t1Level, (int)g_t2Level,
          (g_thrSrc==ThrSrc::T2 ? (g_t2Armed?"ARMED":"UNARMED") : "N/A"));
#endif

    // Apply drive outputs using FNR + effective throttle level
    Drive::apply(g_fnr, effThrLevel);
  }

  // ~50 Hz steering control loop
  static uint32_t t_ctrl = 0;
  if (micros() - t_ctrl >= 20000){
    t_ctrl = micros();
    Steer::tick(MM::g_s1);
  }

  // Blink
  static uint32_t t_led=0;
  static bool led=false;
  if (millis() - t_led >= BLINK_MS){
    t_led = millis();
    led = !led;
    digitalWrite(LED_PIN, led? HIGH:LOW);
  }

  handleUsbCommandsOnce();
}

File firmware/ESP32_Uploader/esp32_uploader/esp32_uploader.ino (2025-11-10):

// ===== App identity =====
#define APP_NAME "ESP32_Uploader"
#define APP_VER  "v1.3.2-2B"   // <-- bumped for Step 2B

// ===== Teensy UART pins (unchanged) =====
#define TEENSY_TX 43
#define TEENSY_RX 44

// ===== Angle sensor wiring =====
// AS5600 on I2C  (SDA = 8, SCL = 9)
// Module's analog/PWM OUT -> GPIO 5  (optional)
#define I2C_SDA_PIN      8
#define I2C_SCL_PIN      9
#define ANGLE_ANALOG_PIN 5

// ===== App print options =====
#define PRINT_OUT5_VOLTS   0   // 0 = hide analog voltage column, 1 = show it
#define PRINT_PERIOD_MS  100   // web/USB console print period

// ===== AS → Teensy emit options =====
#define AS_PUSH_ENABLE        1       // 1 = send AS,<raw>,<deg> to Teensy
#define AS_PUSH_PERIOD_MS     50      // 20 Hz to Teensy
#define AS_DEG_DECIMALS       2       // keep it compact
#define AS_EMIT_WHEN_INVALID  0       // 0 = skip if no fresh reading

// ===== Quiet window after steer direction flip =====
#define QUIET_MS              180     // reuse last-good during motor surge

#include <Arduino.h>
#include <Wire.h>
#include "esp_log.h"            // for esp_log_level_set(...)
#include "secrets.h"            // WIFI_SSID, WIFI_PASS, OTA_TOKEN
#include "esp32_ota_hub.h"      // OTA hub header (with 2 / 2a pacing hardening)

// ---- Web console logging shortcuts (mirror to USB + /esp32-console)
#define LOG(s)        OtaHub::ELOG(s)
#define LOGF(...)     OtaHub::ELOGF(__VA_ARGS__)

// ===== Small shim to talk to Teensy via the hub =====
// Add two tiny helpers in esp32_ota_hub.h (shown below): teensyPrintln(), isTeensyFlashing()
static inline void TeensySendLine(const char* s){
  OtaHub::teensyPrintln(s);   // safe; hub UART already opened at 230400
}
static inline bool TeensyIsFlashing(){
  return OtaHub::isTeensyFlashing();
}

// ===== AS5600 registers / address =====
static const uint8_t  AS5600_ADDR     = 0x36;
static const uint8_t  REG_RAW_ANGLE   = 0x0C;   // 12-bit (0..4095)
static const uint8_t  REG_ANGLE       = 0x0E;   // scaled (also 12-bit)
static const uint32_t I2C_CLK_HZ      = 400000; // 400 kHz
static const uint8_t  I2C_RETRIES     = 3;      // retries per read
static const uint32_t I2C_XFER_TO_MS  = 40;     // per transfer timeout

// ===== Helpers =====
static inline float ticksToDeg(uint16_t t12) { return (360.0f * (float)t12) / 4096.0f; }

// Simple EMA (no templates)
struct EMA {
  float y;
  float alpha;  // 0..1 (higher = snappier)
  EMA(float a=0.20f): y(NAN), alpha(a) {}
  float update(float x) {
    if (isnan(y)) y = x;
    else y = y + alpha * (x - y);
    return y;
  }
};

// ===== Steer flip quieting =====
static volatile uint32_t gSteerFlipMs = 0;
static inline void markSteerFlip() { gSteerFlipMs = millis(); }  // expose for your use

// ===== I2C read with retry (16-bit big-endian register) =====
static bool i2c_read16_retry(uint8_t addr, uint8_t reg, uint16_t& out) {
  for (uint8_t attempt = 0; attempt < I2C_RETRIES; ++attempt) {
    Wire.beginTransmission(addr);
    Wire.write(reg);
    if (Wire.endTransmission(false) != 0) { delay(1); continue; } // repeated start

    int n = Wire.requestFrom((int)addr, 2, (int)true); // stop=true
    if (n == 2) {
      uint8_t hi = Wire.read();
      uint8_t lo = Wire.read();
      out = (uint16_t)((hi << 8) | lo);
      return true;
    }
    delay(1);
  }
  return false;
}

static bool as5600_read_raw(uint16_t& raw12) {
  uint16_t v;
  if (!i2c_read16_retry(AS5600_ADDR, REG_RAW_ANGLE, v)) return false;
  raw12 = (uint16_t)(v & 0x0FFF);
  return true;
}

// ===== Runtime state =====
static EMA   emaDeg(0.20f);     // smoothed degrees
#if PRINT_OUT5_VOLTS
static EMA   emaVolts(0.20f);   // smoothed analog volts
#endif
static uint16_t lastGoodRaw = 0;
static bool     haveGood    = false;
static unsigned long lastPrintMs = 0;

// AS line rate limiter
static unsigned long lastEmitMs = 0;

void setup() {
  Serial.begin(115200);
  delay(150);

  // Mute only the noisy ESP-IDF I2C driver lines, keep your own prints:
  esp_log_level_set("i2c",        ESP_LOG_WARN);
  esp_log_level_set("i2c.master", ESP_LOG_WARN);

  // Bring up OTA hub + web + consoles
  OtaHub::begin(WIFI_SSID, WIFI_PASS, OTA_TOKEN, "esp32-teensy");

  // I2C init
  Wire.begin(I2C_SDA_PIN, I2C_SCL_PIN);
  Wire.setClock(I2C_CLK_HZ);
  Wire.setTimeOut(I2C_XFER_TO_MS);

#if PRINT_OUT5_VOLTS
  analogReadResolution(12);         // 0..4095
  pinMode(ANGLE_ANALOG_PIN, INPUT);
#endif

  LOG("[AS5600] Ready. Keys: (none needed) — printing every 100ms. AS push to Teensy enabled.");
}

void loop() {
  // keep OTA hub alive
  OtaHub::loop();

  const unsigned long now = millis();

  // Decide whether to query I2C this cycle
  const bool inQuiet = (now - gSteerFlipMs) < QUIET_MS;

  uint16_t raw = 0;
  bool readOK = false;

  if (!inQuiet) {
    // Try a live I2C read
    readOK = as5600_read_raw(raw);
    if (readOK) { lastGoodRaw = raw; haveGood = true; }
  } else {
    // In quiet zone: reuse last-good value
    if (haveGood) { raw = lastGoodRaw; readOK = true; }
  }

  // Convert to degree; if no data yet, keep deg as NaN (prints "NaN")
  float deg = NAN;
  if (readOK) {
    deg = ticksToDeg(raw);
    deg = emaDeg.update(deg);
  }

#if PRINT_OUT5_VOLTS
  // Optional analog OUT reading (smoothed)
  int   adc    = analogRead(ANGLE_ANALOG_PIN);
  float volts  = (3.3f * (float)adc) / 4095.0f;
  float v_sm   = emaVolts.update(volts);
#endif

  // ====== 1) Mirror to web/USB console ======
  if ((now - lastPrintMs) >= PRINT_PERIOD_MS) {
    lastPrintMs = now;
    if (readOK) {
    #if PRINT_OUT5_VOLTS
      LOGF("AS5600 raw=%u  deg=%.2f  OUT5=%.3fV", raw, deg, v_sm);
    #else
      LOGF("AS5600 raw=%u  deg=%.2f", raw, deg);
    #endif
    } else {
    #if PRINT_OUT5_VOLTS
      LOGF("AS5600 raw=ERR  deg=NaN  OUT5=%.3fV", v_sm);
    #else
      LOG("AS5600 raw=ERR  deg=NaN");
    #endif
    }
  }

  // ====== 2) Push to Teensy as "AS,<raw>,<deg>" ======
#if AS_PUSH_ENABLE
  const bool okToEmit = readOK || AS_EMIT_WHEN_INVALID;
  if (okToEmit && (now - lastEmitMs) >= AS_PUSH_PERIOD_MS) {
    lastEmitMs = now;

    // If hub is currently flashing the Teensy, pause emissions to avoid line collisions
    if (!TeensyIsFlashing()) {
      char line[40];
      if (readOK) {
        // keep it compact for parser + bandwidth
        dtostrf(deg, 0, AS_DEG_DECIMALS, line);  // temp reuse; we'll overwrite
        // safer build:
        snprintf(line, sizeof(line), "AS,%u,%.2f", (unsigned)raw, (double)deg);
      } else {
        // If ever allowed, you could emit a sentinel here (we default to skip)
        snprintf(line, sizeof(line), "AS,ERR,NaN");
      }
      TeensySendLine(line);   // goes to UART1 (RX=44, TX=43) via hub
    }
  }
#endif
}
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

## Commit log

2025-10-26 Implement transparent telnet bridge and quiet Teensy console
2025-10-26 Fix telnet double echo and stream handling
    [esp32_uploader.ino]
2025-10-26 Simplify Teensy OTA pipeline
2025-10-27 Improve ESP32↔Teensy OTA handshake logging
2025-10-31 Add Teensy 4.1 OTA update loader
2025-10-31 Move OTA runtime into teensystub sketch
2025-10-31 Make Teensy OTA runtime Arduino-friendly
2025-10-31 Provide CMSIS fallback for Teensy OTA build
2025-10-31 Implement Teensy OTA flashing and update docs
2025-10-31 Add ESP32 OTA protocol support to FlasherX
2025-10-31 ESP32 UPDATE1!!
2025-11-09 Improve Teensy console stability and add clear control
    [MyApp.ino, esp32_ota_hub.h]
2025-11-09 Slow raw stream, faster UART, add telemetry
2025-11-09 Filter Teensy telemetry bytes during HELLO handshake
2025-11-09 Adjust ESP32 OTA hub include guard
2025-11-09 Restore telemetry parser state reset
    [esp32_ota_hub.h]
2025-11-09 Disable Teensy binary telemetry by default
2025-11-09 Fix Teensy console drain to preserve logs
    [esp32_ota_hub.h]
